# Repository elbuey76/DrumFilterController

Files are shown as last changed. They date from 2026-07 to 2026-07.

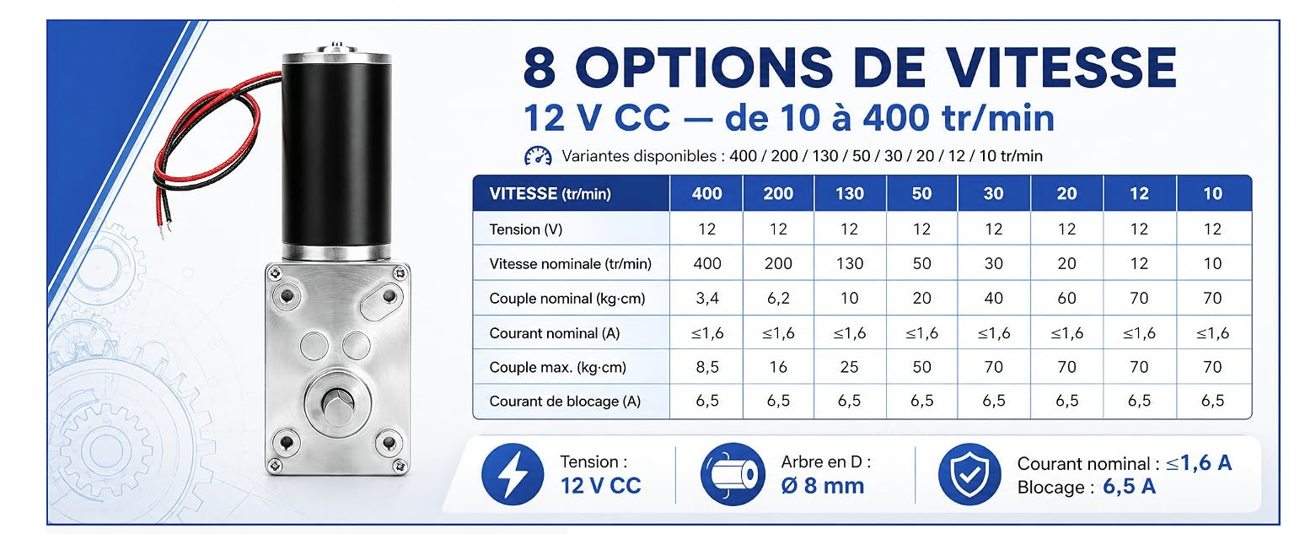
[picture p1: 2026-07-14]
docs/assets/fyearfly-12v-motor-speed-options.png

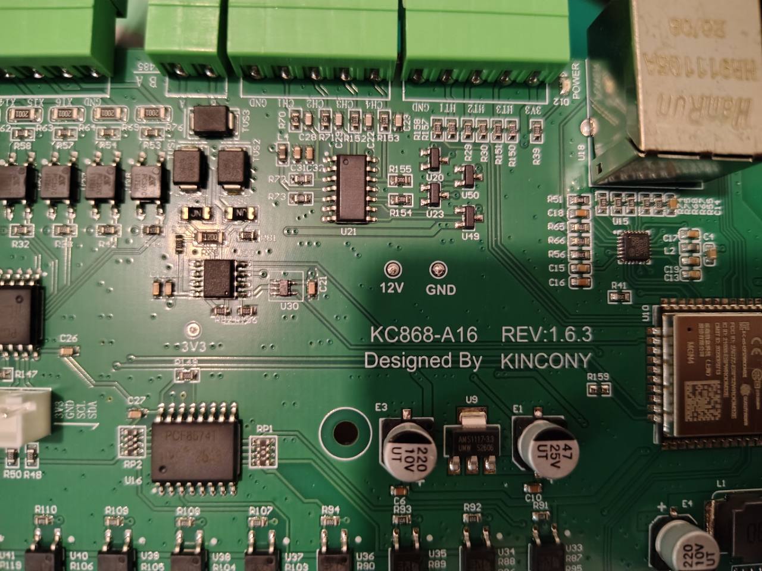
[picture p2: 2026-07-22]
.codex-remote-attachments/019f6168-8cca-70a1-9c1a-e4df0d75bf8c/e161524b-0c4d-4f39-874e-5306fa50447a/1-Photo-1.jpg

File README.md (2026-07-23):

# Contrôleur de filtre à tambour pour bassin

Ce dépôt accueillera la documentation, les schémas, les décisions de conception et le logiciel d'un contrôleur de filtre à tambour pour bassin. L'objectif est de construire un système fiable, maintenable et documenté, basé autant que possible sur des cartes électroniques du commerce, avec la possibilité de concevoir une carte dédiée si le besoin devient justifié.

## Organisation du dépôt

| Dossier | Rôle |
| --- | --- |
| `docs/specification/` | Spécification fonctionnelle, exigences, contraintes et questions ouvertes. |
| `docs/calculs/` | Notes de calcul de dimensionnement hydraulique, mécanique et électrique. |
| `docs/architecture/` | Architecture système, matérielle et logicielle, avec diagrammes et emplacements pour visuels. |
| `docs/decisions/` | Journal de décisions de type ADR pour garder l'historique des choix importants. |
| `docs/achats/` | Listes de course, nomenclatures et points de commande matériel. |
| `docs/backlog/` | Backlog de cadrage, prototype, firmware, documentation et validation. |
| `docs/firmware/` | Plans de réalisation et de découpage du firmware. |
| `docs/validation/` | Plan de tests, traçabilité exigences/preuves et résultats de validation. |

Les documents de spécification et d'architecture sont rédigés en Markdown pour pouvoir combiner texte, tableaux, diagrammes Mermaid et images stockées dans les dossiers `assets/`.

## Objectifs du projet

Le contrôleur doit automatiser le nettoyage d'un filtre à tambour en surveillant le niveau d'eau dans le FAT, puis en déclenchant une rotation du tambour et une pompe de rinçage lorsque le seuil de lavage est atteint. Il doit aussi protéger l'installation en détectant les défauts, couper des prises auxiliaires en cas de niveau bas, permettre un fonctionnement manuel, gérer des modes maintenance, dégradé et test, et redémarrer proprement après une coupure de courant.

Les objectifs principaux sont :

- automatiser les cycles de lavage du tambour ;
- détecter un seuil de niveau haut déclenchant le lavage et un seuil de niveau bas de sécurité ;
- limiter la consommation d'eau et d'énergie ;
- protéger la pompe, le moteur et le bassin en cas de défaut ;
- permettre des modes auto, manuel, maintenance, dégradé et test avec comportements explicites ;
- garder une architecture compréhensible et réparable ;
- préparer une évolution vers journalisation, écran local, supervision réseau et notifications à distance.

## Documents de départ

- [Spécification fonctionnelle](docs/specification/README.md)
- [Notes de calcul](docs/calculs/README.md)
- [Architecture](docs/architecture/README.md)
- [Journal de décisions](docs/decisions/README.md)
- [Achats](docs/achats/README.md)
- [Backlog](docs/backlog/backlog.md)
- [Firmware](docs/firmware/README.md)
- [Validation](docs/validation/README.md)

## Prochaine étape

La validation E/S de la KC868-A16 **REV.1.6.3** recuee est terminee a vide : `X1-X16`, boot OFF et impulsions isolees `Y1-Y16` sont confirmes. Les deux DS18B20 sont lues et associees par ROM. La prochaine etape est le test des voyants et bobines, une par une apres mesure de courant et verification des suppressions de surtension, puis LCD 2004 I2C et RTC DS3231. Le profil materiel reste desarme jusqu'a ces preuves ; voir [VR-0001](docs/validation/VR-0001-reception-kc868-a16-rev1.6.3.md).

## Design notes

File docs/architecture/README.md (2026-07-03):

# Architecture

Ce dossier documenté l'architecture matérielle, électronique et logicielle. Le format principal est Markdown avec schémas Mermaid intégrés et possibilité d'ajouter des images dans `assets/` ou des sources de diagrammes dans `diagrams/`.

## Documents

1. [Vue d'ensemble](01-vue-ensemble.md)
2. [Architecture matérielle](02-architecture-materielle.md)
3. [Architecture logicielle](03-architecture-logicielle.md)
4. [Table des entrées / sorties](04-table-entrees-sorties.md)

## Visuels

- `assets/` : images exportées, photos de prototype, croquis scannés.
- `diagrams/` : sources de diagrammes, par exemple Mermaid, Draw.io ou KiCad exporté.

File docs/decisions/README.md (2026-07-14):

# Journal de décisions

Ce dossier contient les décisions structurantes du projet. Chaque decision importante doit être ajoutée sous forme d'ADR afin de conserver le contexte et les raisons du choix.

## Convention de nommage

```text
ADR-0001-titre-court.md
ADR-0002-titre-court.md
```

## Statuts possibles

- Proposee
- Acceptée
- Remplacée
- Abandonnee

## Modèle rapide

Copier le fichier `_template.md` pour créer une nouvelle decision.

## Decisions disponibles

1. [ADR-0001 - Structurer la documentation projet en Markdown](ADR-0001-structure-documentation.md)
2. [ADR-0002 - Dimensionner la pompe principale sur une pompe variable avec marge](ADR-0002-dimensionnement-pompe-filtration-principale.md)
3. [ADR-0003 - Choix de la plateforme de contrôle V1](ADR-0003-choix-plateforme-controle-v1.md)
4. [ADR-0004 - Architecture electrique V1](ADR-0004-architecture-electrique-v1.md)
5. [ADR-0005 - Choix de la RTC pour l'heure fiable](ADR-0005-choix-rtc-heure-fiable.md)
6. [ADR-0006 - Choix des sondes de temperature](ADR-0006-choix-sondes-temperature.md)
7. [ADR-0007 - Choix du contact de capot](ADR-0007-choix-contact-capot.md)
8. [ADR-0008 - Choix des voyants de l'IHM locale](ADR-0008-choix-voyants-ihm-locale.md)
9. [ADR-0009 - Choix du sélecteur de mode AUTO / MAINTENANCE](ADR-0009-choix-selecteur-mode-auto-maintenance.md)
10. [ADR-0010 - Choix des boutons poussoirs de l'IHM locale](ADR-0010-choix-boutons-poussoirs-ihm-locale.md)
11. [ADR-0011 - Strategie de validation materielle V1](ADR-0011-strategie-validation-materielle-v1.md)
12. [ADR-0012 - Migration de la plateforme KC868-A32 vers KC868-A16](ADR-0012-migration-kc868-a32-vers-a16.md)

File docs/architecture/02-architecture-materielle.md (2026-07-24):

# Architecture matérielle

## Blocs materiels

| Bloc | Rôle | Options envisagées |
| --- | --- | --- |
| Carte de contrôle | Exécute la logique de lavage et sécurité | KC868-A16 ESP32 classique REV.1.6.3 recuee pour la V1 |
| Entrées capteurs | Detectent niveau de lavage, niveau critique, capot, température bassin et température ambiante | Flotteurs, capteurs pression, inductifs, contacts secs, sondes de température |
| Sorties puissance | Pilotent pompe, moteur et prises auxiliaires | Sorties MOSFET 12 VDC vers relais HELLA, contacteurs TOMZN et relais d'interface du contacteur Schneider 230 VAC |
| Interface locale | Permet conduite, signalisation et diagnostic | LCD 2004 / 20x4 I2C 3,3 V, boutons, voyants |
| Communication distante | Option V2 pour supervision et notifications à distance | Wi-Fi cible ; BLE seul insuffisant, Ethernet non disponible sur site, SMS non retenu par défaut |
| Temps fiable | Support futur d'horodatage V2 | Module RTC DS3231 I2C 3,3 V avec batterie rechargeable ; synchronisation réseau possible plus tard en complement, sans dependance exclusive à Internet |
| Alimentation | Fournit basse tension stable | 12 VDC retenu via Mean Well NDR-120-12, 120 W, 10 A |

## Composants materiels deja choisis

| Sous-ensemble | Choix retenu | Impact de conception |
| --- | --- | --- |
| Toile de filtration tambour | Inox 74 microns | Fixe la finesse de filtration mécanique de référence |
| Capteurs de niveau | CR18-8DN | Imposent une interface d'entrée compatible NPN, 12-24 VDC, 3 fils |
| Plateforme de contrôle | KC868-A16 ESP32 classique REV.1.6.3, 16 entrees `X1` a `X16` et 16 sorties MOSFET `Y1` a `Y16` 12/24 VDC | Carte recue et validee a vide le 2026-07-22 ; couvre les 9 entrees et 9 sorties V1 avec 7 voies libres de chaque type ; remplace l'A32 surdimensionnee selon ADR-0012. Les charges et auxiliaires restent a valider. |
| Alimentation 12 VDC | Mean Well NDR-120-12, 120 W, 10 A, rail DIN | Alimente automate, capteurs, IHM, accessoires et moteur tambour via départs fusibles |
| Porte-fusibles 12 VDC | Porte-fusibles ATO 4 emplacements | Distribution 12 VDC ; adaptateur rail DIN imprime 3D realise et fonctionnel |
| Moteur tambour | Motorreducteur Fyearfly 12 VDC 10 rpm | Simplifie la vitesse de tambour par rapport au moteur d'essuie-glace candidat |
| Relais moteur tambour | HELLA 4RD 933 332-551, 12 V, charge inductive 15 A | Commande le moteur tambour ; support rail DIN imprime 3D realise et fonctionnel |
| Pompe de rinçage | VEVOR / Leo EKJ-802S, 220-240 VAC, 800 W indique projet | Impose une commande secteur adaptée à une charge moteur et une mesure du débit réel sur la rampe et les buses déjà achetées et fabriquées |
| Contacteur pompe de rinçage | Schneider Electric TeSys LC1D18P7, 3P, AC-3 18 A, bobine 230 VAC | Sa bobine 230 VAC est commandee par le contact d'un relais d'interface a bobine 12 VDC, lui-meme pilote par une sortie MOSFET A16 ; reference du relais a choisir et valider |
| Contacteurs filtration, UV, décoration, mise à niveau | TOMZN TOCT1-25Z, 25 A, bobine 12 VDC | Pilotés directement en 12 VDC par les sorties MOSFET de l'A16 si la mesure confirme moins de 500 mA par bobine, avec suppression de surtension adaptee |
| Ecran local | LCD 2004 / 20x4 I2C 3,3 V, fond bleu retenu | Afficheur texte principal de l'IHM locale ; raccordement cible sur un bus I2C auxiliaire separe via `GPIO32` / `GPIO33` de l'A16, sans charger le bus I2C interne des entrees/sorties |
| Horloge temps reel | Module RTC DS3231 I2C 3,3 V avec batterie rechargeable | Source locale d'heure fiable pour V2, et horodatage MVP seulement si simple ; adresse I2C attendue `0x68`, raccordement cible sur le bus I2C auxiliaire du port d'extension si la cohabitation avec le LCD est validee |
| Sondes de temperature | 2 x DS18B20 étanches inox 3 fils, longueur cible 3 m | Meme modele pour `TEMP_BASSIN` et `TEMP_LOCAL` ; alimentation 3,3 V, pull-up 4,7 kΩ sur `DATA`. Brochage banc confirme : rouge VCC, noir GND, jaune DATA ; ROMs associees par role. |

## Carte KC868-A16 effectivement recue

La carte disponible est une **Kincony KC868-A16 REV.1.6.3**, a ESP32-WROOM-32 classique. Le test `kc868_a16_hw_safe` du 2026-07-22 a confirme le bus interne `GPIO4/GPIO5` et les quatre adresses `0x21`, `0x22`, `0x24`, `0x25`. Les essais par contact sec ont confirme que `0x22` lit physiquement `X1` a `X8`, puis `0x21` lit `X9` a `X16`. La serigraphie physique utilise `X1` a `X16` pour les entrees et `Y1` a `Y16` pour les sorties MOSFET. Les aliases firmware `I1` a `I9` et `O1` a `O9` suivent respectivement `X1` a `X9` et `Y1` a `Y9`.

Le test a ecrit l'etat brut OFF `0xFF 0xFF` aux deux banques de sorties et le build safe a refuse toute sortie appliquee. Avec les groupes de sorties alimentes en 12 V et sans charge, chaque borne `Y` mesure 100 a 200 mV au boot : l'etat OFF physique est confirme. Les impulsions de banc ont ensuite valide la polarite active et la commande individuelle isolee de `Y1-Y16`. Voir [VR-0001](../validation/VR-0001-reception-kc868-a16-rev1.6.3.md).

## Données hydrauliques d'entrée

L'installation cible a contrôler comprend un FAT avec :

- une emprise interne totale de 78 cm x 47 cm ;
- un trop-plein physique fixe à 30,5 cm de hauteur d'eau ;
- un compartiment eau propre de 62 cm x 47 cm contenant un tambour de 31 cm de diamètre sur 57 cm de longueur utile ;
- deux entrées de 110 mm : une bonde de fond et un skimmer ;
- deux sorties de 110 mm pour conserver le flux hydraulique ;
- une goutiere d'évacuation des dechets rinces vers un tuyau de 100 mm ;
- un report de niveau côté eau propre via un tube de 32 mm ;
- une rampe d'aspersion en 32 mm avec buses.

La rotation du tambour est retenue avec un motorreducteur Fyearfly 12 VDC 10 rpm, en fonctionnement intermittent pendant les cycles de lavage, tests ou commandes manuelles autorisées. Ce choix remplace le candidat initial de moteur d'essuie-glace SWF 403.835 et évite de dépendre d'une réduction mécanique importante pour atteindre une vitesse exploitable.

Le rinçage est envisagé avec une pompe de surface VEVOR / Leo EKJ-802S en 220-240 VAC. La rampe d'aspersion 32 mm et les buses sont déjà achetées et fabriquées ; elles font donc partie du périmètre matériel MVP. La courbe disponible indique environ 3,6 m3/h a très faible hauteur utile et environ 2,4 m3/h à 21 m ; le débit effectif devra être mesuré sur cette rampe réelle.

Le FAT sera installe dans un local de filtration maconne, isole en XPS 5 cm, sans pluie directe sur le FAT. Un capot transparent relevable est prévu au-dessus du petit batiment pour permettre de voir le tambour tourner sans ouvrir le FAT ; ce capot et le couvercle transparent désignent la même pièce physique. Sa matiere et son niveau d'isolation restent à définir.

Ces données doivent être prises en compte pour les choix de capteurs, l'implantation du niveau de lavage côté eau propre, l'ajout d'une mesure de température bassin, l'ajout d'une mesure de température ambiante local et les contraintes de débit autour du filtre.

La liste de signaux à prévoir pour le MVP est détaillée dans [04-table-entrees-sorties.md](04-table-entrees-sorties.md).

## Chaine hydraulique de référence

```mermaid
flowchart LR
    Bassin["Bassin 186 x 411 x 108 cm"]
    BF["Bonde de fond 110 mm"]
    SK["Skimmer 110 mm"]
    FAT["FAT gravitaire"]
    IBC["IBC 1000 L + tapis japonais"]
    PF["Pompe filtration"]
    Retour["Retour bassin 63 mm"]
    PD["Pompe décoration"]
    Deco["Cascade / mur d'eau / lame d'eau"]
    UV["UV hors tambour (apres pompe)"]
    Waste["Goutiere + evacuation 100 mm"]

    Bassin --> BF --> FAT
    Bassin --> SK --> FAT
    FAT --> IBC --> PF --> UV --> Retour --> Bassin
    IBC --> PD --> Deco
    FAT --> Waste
```

## Interfaces mécaniques et instrumentation

| Sous-ensemble | Interface connue | Impact de conception |
| --- | --- | --- |
| Tube de report de niveau | 32 mm, bouche en partie haute avec event de 1 mm | Permet une fixation protégée des deux capteurs côté eau propre EP_LAVAGE et EP_CRITIQUE, et facilite le nettoyage |
| Capteurs de niveau | 2 x CR18-8DN câblés en MVP, M18, distance ajustable 8 mm, sortie NPN normalement ouverte, alimentation 12-24 VDC, 10 mA max, DC 3 fils | EP_LAVAGE au-dessus de EP_CRITIQUE sur supports réglables en hauteur ; réserve mécanique non câblée possible pour un troisième capteur futur ; interface directe sur entrées digitales KC868-A16 retenue par défaut, avec validation banc obligatoire avant câblage final |
| Goutiere de trop-plein | seuil fixe à 30,5 cm | Fixe la cote maximale exploitable pour les seuils de pilotage |
| Support du FAT | a fabriquer | Conditionne tout le régime gravitaire par rapport au bassin |
| Capot | à créer avec fin de course OMRCH ME-8104, contact `1NO1NC` | Ajoute l'entrée de sécurité `CAPOT_OUVERT`. Le montage doit donner capot fermé = boucle fermée, capot ouvert ou fil coupé = boucle ouverte ; choix `NO` ou `NC` à valider au multimètre selon la mécanique réelle. |
| Joint a levre tambour | a poser | Indispensable pour separer correctement eau sale et eau propre |
| Moteur tambour | Fyearfly 12 VDC 10 rpm | Courant réel, couple disponible, sens de rotation et fixation mécanique à valider avant schéma définitif |
| Transmission tambour | A définir autour du motorreducteur 10 rpm | La vitesse finale tambour doit être validée en essai réel ; la réduction 3:1 du candidat SWF n'est plus l'hypothèse de base |
| Protection moteur tambour | Fusible ATO 5 A sur le départ moteur et relais HELLA 12 V 15 A inductif | Courant de blocage annoncé 6,5 A d'après screenshot fournisseur ; calibre 5 A retenu pour essai ; comportement réel de protection à vérifier sur montage MVP |
| Pompe de rinçage | VEVOR / Leo EKJ-802S, raccords 1 pouce, IPX4, classe I | Pompe 230 VAC de surface, a protéger electriquement et a maintenir hors immersion |
| Rampe de rinçage | Tuyau 32 mm + buses déjà achetés et fabriqués | Le point débit/pression réel de la pompe devra être mesuré sur cet ensemble |
| Sonde température bassin | DS18B20 étanche inox 3 fils, longueur cible 3 m | A implanter dans une eau représentative : arrivée gravitaire avant pompe/UV ou bassin en zone brassée, ombragée et accessible ; montage protégé et démontable ; alimentation 3,3 V, pull-up 4,7 kΩ sur `DATA` ; alerte informative en V1 avec seuils initiaux < 4 deg C et > 28 deg C |
| Sonde température ambiante local | DS18B20 étanche inox 3 fils, longueur cible 3 m, même modèle que la sonde bassin | Hors coffret, dans l'air du local, loin de l'alimentation, des contacteurs, des pompes, du soleil et du volume chaud sous capot ; support ventilé et accessible pour conserver une mesure d'air représentative ; alerte informative en V1 avec seuils initiaux < 2 deg C et > 40 deg C |
| IHM locale | LCD 2004 / 20x4 I2C 3,3 V, commandes physiques, voyants MARCHE, ALARME et LAVAGE | L'écran porte le détail ; raccordement cible sur `GPIO32` / `GPIO33` des ports capteurs KC868-A16 via un bus I2C auxiliaire separe ; sélecteur AUTO / MAINTENANCE 22 mm 2 positions maintenues `1NO + 1NC` ; boutons poussoirs 22 mm momentanés `1NO1NC` : reset bleu, test jaune, manuel tambour noir, manuel rinçage noir ; voyants LED étanches 16 mm 12 VDC retenus pour le MVP : MARCHE vert, ALARME rouge et LAVAGE jaune |
| Liaison distante | option V2 Wi-Fi | Le matériel MVP est la base définitive de la V2 et doit être prêt pour une V2 Wi-Fi sans remplacement de plateforme principale ; la notification ne doit pas compromettre le fonctionnement local |
| Horloge fiable | RTC DS3231 retenue, implementation MVP optionnelle | Module RTC DS3231 I2C 3,3 V avec batterie rechargeable, adresse attendue `0x68`. Raccordement cible sur `GPIO32` / `GPIO33` de la KC868-A16 via un bus I2C auxiliaire separe, partage possible avec le LCD 2004 si les essais confirment pull-up 3,3 V, adresses distinctes et stabilite. Sert au temps civil, aux logs et aux statistiques ; les temporisations de securite restent sur timers internes. |
| Position tambour | option V1.1 à étudier | Peut aider pour l'indexation et certains diagnostics avances |

L'UV est retenu hors tambour dans la chaine de filtration, après la pompe principale. Il reste asservi à la filtration autorisée et à l'absence de EP_CRITIQUE ; il n'est pas coupé sur un défaut FAT non critique si la filtration reste autorisée.

## Architecture electrique retenue V1

La decision de reference est [ADR-0004 - Architecture electrique V1](../decisions/ADR-0004-architecture-electrique-v1.md).

La commande matérielle visée correspond au MVP définitif, pas à une commande d'essais séparée. Les validations restantes servent à figer le schéma, les protections, les réglages et l'implantation, en conservant la même plateforme matérielle pour la V2.

### Tableau 230 VAC

| Depart | Protection retenue | Equipements | Commentaire |
| --- | --- | --- | --- |
| Protection amont cote maison | Disjoncteur dedie 16 A | Liaison maison vers coffret filtration | Liaison confirmee en 3G2,5 mm2, actuellement en attente et sans disjoncteur au tableau maison. Le disjoncteur 16 A doit etre ajoute avant le raccordement du coffret. |
| Tete de tableau | Interrupteur differentiel 2P 30 mA, 40 A, type A | Tableau local complet | Choix coherent avec les charges reelles du MVP ; la notice AquaForte DM-Vario demande 30 mA sans imposer type F ou B. |
| Alimentation 12 VDC | Disjoncteur 4 A courbe C | Mean Well NDR-120-12 | Depart dedie au controle basse tension. |
| Pompe de rincage | Disjoncteur 6 A courbe C | Pompe VEVOR / Leo EKJ-802S sur prise 16 A commandee | Commande par contacteur Schneider LC1D18P7, bobine 230 VAC. Le courant nominal pompe est 3,5 A ; le 6 A C remplace le 10 A pour une protection plus ajustee du depart. |
| Prises local | Disjoncteur 16 A courbe C | 1 prise bulleur bassin, 1 prise bulleur bio, 2 prises maintenance | Les bulleurs et prises maintenance sont permanents, hors controleur. |
| Pompe filtration | Disjoncteur 6 A courbe C | Pompe principale sur prise 16 A commandee | Depart separe et prioritaire car organe essentiel. |
| UV, pompe decoration, mise a niveau | Disjoncteur 6 A courbe C | UV et pompe decoration sur prises 16 A commandées ; mise a niveau a definir | Separé de la filtration afin qu'un defaut sur un organe non essentiel ne coupe pas la pompe de filtration. |
| Eclairage exterieur | Disjoncteur 6 A courbe C | 6 spots LED exterieurs 3 W avec detecteurs | Depart distinct hors automatisme FAT ; charge nominale 18 W, soit environ 0,08 A sous 230 VAC, avec environ 10 a 15 m de cable. |

### Distribution 12 VDC

| Depart 12 VDC | Fusible | Usage |
| --- | --- | --- |
| Moteur tambour | 5 A | Motorreducteur Fyearfly 12 VDC 10 rpm via relais HELLA |
| Automate | 3 A | KC868-A16, alimentation principale et deux alimentations des banques de sorties selon schema final |
| Capteurs et boutons | 1 A | Capteurs de niveau, capot et commandes locales |
| Ecran, voyants, accessoires | 1 A | IHM locale, signalisation et accessoires |

Le porte-fusibles ATO devra etre fixe proprement dans le coffret. Les quatre departs 12 VDC proteges partent directement de ce porte-fusibles vers leurs charges : aucun repartiteur +12 V / 0 V supplementaire n'est prevu. Si le modele ATO 4 emplacements est conserve et n'a pas de fixation rail DIN native, un adaptateur imprime en 3D uniquement mecanique sera concu pour assurer le maintien, l'acces aux fusibles, l'absence de contrainte sur les cosses et le reperage des quatre departs.

### Cablage interne basse tension et facade

- Utiliser du fil souple **H07V-K 0,5 mm2** pour les signaux TBT, les capteurs,
  les boutons et les voyants, dans les goulottes basse tension.
- Utiliser du **H07V-K 0,75 mm2** pour l'alimentation de la KC868-A16 et les
  bobines 12 VDC, sous reserve de mesure du courant reel des bobines.
- Le moteur tambour conserve son cable **2 x 2,5 mm2** dedie ; son retour `0 V`
  revient directement vers la distribution 12 VDC et ne partage pas le petit
  commun de commande.
- Pour la porte, utiliser un cable souple multiconducteur **16 x 0,25 ou
  0,34 mm2**, fixe avec serre-cable et boucle de service cote charniere.
- Un unique `0 V` commun de 0,5 mm2 peut etre partage par le LCD, les contacts
  secs du selecteur/boutons et les trois voyants. Les boutons ne recoivent pas
  de 12 V : ils ramenent simplement leur entree KC868-A16 vers ce `0 V`.
- Le LCD reste alimente en **3,3 V** et utilise `SDA` / `SCL`; seuls les voyants
  utilisent les sorties 12 VDC de la KC868-A16. Ne pas employer le bleu pour le
  `0 V` continu, car il est reserve au neutre 230 VAC dans ce coffret.

### Interface des capteurs CR18-8DN

Les entrees digitales du KC868-A16 sont optocouplees et prevues pour des contacts ramenes vers `GND`. Le CR18-8DN fournit une sortie `NPN` collecteur ouvert : marron sur `+12 VDC`, bleu sur `0 V`, noir vers l'entree digitale.

Le cablage direct est retenu en premiere intention pour `EP_LAVAGE` et `EP_CRITIQUE`, sans relais d'interface ni conditionneur supplementaire. Cette decision reste soumise a un test banc avec les vrais capteurs et la revision A16 recue, afin de confirmer le courant d'entree, le sens logique, la stabilite de lecture, le comportement en fil coupe et l'absence de declenchements parasites avec les longueurs de cable reelles.

### Interface du contact de capot

Le contact de capot V1 retenu est un fin de course industriel OMRCH `ME-8104`, momentane, avec contact `1NO1NC`. Il est raccorde comme un contact sec vers `GND` sur une entree digitale du KC868-A16.

Le comportement fonctionnel attendu est : capot ferme = boucle fermee vers l'entree automate ; capot ouvert, fil coupe ou connecteur debranche = boucle ouverte. Le choix pratique entre les bornes `NO` et `NC` du `ME-8104` doit etre valide au multimetre apres montage mecanique, car le nom des bornes decrit l'etat du switch au repos, pas forcement l'etat capot ferme.

Le fin de course doit etre fixe sur la partie fixe du bâti ou du petit batiment, et actionne par une patte ou came reglable solidaire du capot transparent. Le reglage doit eviter qu'un capot entrouvert soit interprete comme ferme.

### Interface de l'ecran local

L'ecran local V1 retenu est un LCD 2004 / 20x4 I2C 3,3 V, fond bleu, avec module I2C de type PCF8574 ou equivalent. Il est alimente par le depart 12 VDC `Ecran, voyants, accessoires` seulement si le module integre une regulation adaptee ; par defaut, son alimentation logique et ses lignes I2C doivent rester compatibles 3,3 V.

Le raccordement cible utilise deux des trois GPIO capteurs de la KC868-A16, avec `GPIO32` et `GPIO33` affectes a un bus I2C auxiliaire separe porte par le second controleur `TwoWire` de l'ESP32. Ce choix evite d'ajouter un peripherique sur le bus I2C interne deja utilise par les PCF8574 des sorties et des entrees digitales. Le brochage de la revision recue et l'ordre exact `SDA` / `SCL` seront figes dans le firmware et le schema apres validation banc.

La validation banc doit verifier l'adresse I2C reelle, probablement `0x27` ou `0x3F`, le contraste, le retroeclairage, la lisibilite en facade, le comportement au redemarrage et l'absence de pull-up vers 5 V sur `SDA` / `SCL`. Si le module recu n'est pas reellement compatible 3,3 V, ajouter un convertisseur de niveau I2C 3,3 V / 5 V ou remplacer le module par une version 3,3 V confirmee.

### Interface de l'horloge RTC

L'heure fiable V2 retenue est un module RTC DS3231 I2C 3,3 V avec batterie rechargeable. Le module doit etre alimente en 3,3 V cote KC868-A16 / ESP32, avec `SDA` et `SCL` tires au 3,3 V uniquement. L'adresse I2C attendue est `0x68`.

Le raccordement cible reutilise le bus I2C auxiliaire separe du port d'extension `GPIO32` / `GPIO33`, partage avec le LCD 2004 I2C si la validation banc confirme la stabilite du bus et l'absence de conflit d'adresse. Si la cohabitation LCD + RTC est instable, la RTC devra etre deplacee sur un autre bus I2C si des GPIO libres le permettent.

La batterie rechargeable livree avec le module sert a conserver l'heure pendant les coupures d'alimentation principale. Le banc doit confirmer que la cellule livree est bien rechargeable, que l'heure est conservee apres coupure et que le module ne presente pas de pull-up I2C vers 5 V.

### Interface des sondes de temperature

Les deux sondes de temperature V1 retenues sont des DS18B20 etanches inox 3 fils, longueur cible 3 m. Le meme modele est utilise pour le bassin et pour le local afin de simplifier l'achat, le stock de rechange, le cablage et le firmware.

Le raccordement retenu est un bus 1-Wire commun alimente en 3,3 V, sans mode parasite : `VCC` sur `3.3 V`, `GND` sur `0 V` commun, `DATA` sur `GPIO14` de la KC868-A16, avec une resistance de pull-up `4,7 kΩ` entre `DATA` et `3.3 V`. Sur la KC868-A16, le bornier utilisateur `HT3` (parfois marque `GPIO3`) correspond a `GPIO14` ; il ne faut jamais utiliser l'entree optocouplee `X14`. Le brochage confirme est rouge = `VCC`, noir = `GND`, jaune = `DATA`. Les ROMs sont figees dans le profil : `TEMP_BASSIN = 28A3AFC800000062`, `TEMP_LOCAL = 284C19CC000000B2`; les deux lectures et leur role ont ete valides par rechauffement doux.

Si des GPIO libres sont disponibles, la preference est de separer `TEMP_BASSIN` et `TEMP_LOCAL` sur deux bus 1-Wire distincts. Si les GPIO sont limites, un bus commun reste acceptable en V1 puisque ces alertes sont informatives et non bloquantes.

Les couleurs de fils annoncees par les vendeurs ne doivent pas etre prises comme reference unique. Le banc doit verifier le brochage reel de chaque lot avant cablage definitif, ainsi que l'identification stable des sondes pour ne pas inverser eau et local dans le firmware.

### Commandes de puissance

| Organe | Commande automate | Organe de puissance retenu | Remarque |
| --- | --- | --- | --- |
| Moteur tambour | Sortie MOSFET A16 12 VDC vers bobine HELLA | Relais HELLA 4RD 933 332-551, 12 V, 15 A inductif | Mesurer le courant de bobine, ajouter la suppression adaptee si absente et imprimer le support rail DIN. |
| Pompe de rincage | Sortie MOSFET A16 vers relais d'interface 12 VDC, puis contact 230 VAC vers bobine LC1D18P7 | Contacteur moteur Schneider TeSys LC1D18P7, AC-3 18 A | Relais d'interface rail DIN a choisir avec contact `AC-15 >= 1 A sous 230 VAC` ; separation BT/secteur obligatoire. |
| Pompe filtration | Sortie MOSFET A16 12 VDC | Contacteur modulaire TOMZN TOCT1-25Z 25 A | Valider courant de bobine inferieur a 500 mA et suppression de surtension. |
| UV | Sortie MOSFET A16 12 VDC | Contacteur modulaire TOMZN TOCT1-25Z 25 A | Valider courant de bobine inferieur a 500 mA ; asservi a la filtration autorisee et a EP_CRITIQUE absent. |
| Pompe decoration | Sortie MOSFET A16 12 VDC | Contacteur modulaire TOMZN TOCT1-25Z 25 A | Valider courant de bobine inferieur a 500 mA ; suit les memes securites hydrauliques que la filtration. |
| Mise a niveau | Sortie MOSFET A16 12 VDC | Contacteur modulaire TOMZN TOCT1-25Z 25 A ou sortie equivalente | Valider courant de bobine inferieur a 500 mA ; coupee sur EP_CRITIQUE. |

## Schéma de principe

```mermaid
flowchart TB
    subgraph BT[Basse tension]
        Alim[Mean Well NDR-120-12]
        Fusibles[Porte-fusibles ATO 4 departs]
        MCU[KC868-A16]
        Inputs[Entrees capteurs]
        UI[Commandes, LCD 2004 I2C et voyants complémentaires]
    end

    subgraph P[Puissance]
        Diff[Differentiel 30 mA]
        DJ[Disjoncteurs 4A, 6A, 10A, 16A]
        KFiltration[Contacteur TOMZN filtration]
        KRincage[Contacteur Schneider rincage]
        KTOMZN[Contacteurs TOMZN UV/deco/mise a niveau]
        KTambour[Relais HELLA tambour]
    end

    Diff --> DJ
    DJ --> Alim
    Alim --> Fusibles
    Fusibles --> MCU
    Fusibles --> KTambour
    Inputs --> MCU
    UI <--> MCU
    MCU --> KFiltration
    MCU --> KRincage
    MCU --> KTOMZN
    MCU --> KTambour
    DJ --> KFiltration
    DJ --> KRincage
    DJ --> KTOMZN
```

## Decisions matérielles a prendre

- reference finale de l'interrupteur differentiel 2P 30 mA, 40 A, type A ;
- cotes exactes EP_LAVAGE et EP_CRITIQUE sur le tube de report après mesure du niveau normal réel ;
- courant réel, fixation et sens de rotation du motorreducteur Fyearfly 12 VDC 10 rpm ;
- validation du fusible 5 A moteur tambour en référence au courant de blocage annoncé 6,5 A, avec mesure du courant en charge et vérification du comportement en blocage ;
- commande secteur de la pompe de rinçage, raccordement à la terre et validation du contacteur Schneider LC1D18P7 dans le schema final ;
- débit ou pression de rinçage de référence après mesure sur la rampe et les buses déjà fabriquées ;
- mesure terrain de la cote support FAT avant fabrication, afin d'aligner trop-plein physique et niveau hydraulique cible du bassin ;
- calcul final de la geometrie des ouvertures du tambour avant découpe ou perçage, avec objectif 0,20 à 0,23 m2 de surface filtrante utile ;
- validation banc des deux sondes DS18B20 étanches inox : brochage réel des fils, alimentation 3,3 V, pull-up 4,7 kΩ, lecture stable, perte de sonde et identification eau/local ;
- validation banc du LCD 2004 I2C 3,3 V : adresse, contraste, lisibilite, pull-up I2C et affectation `GPIO32` / `GPIO33` ;
- validation banc de la RTC DS3231 I2C 3,3 V : adresse `0x68`, batterie rechargeable livree, conservation de l'heure apres coupure, pull-up I2C 3,3 V et cohabitation avec le LCD 2004 sur `GPIO32` / `GPIO33` ;
- validation des références finales des voyants LED étanches 16 mm 12 VDC : MARCHE vert, ALARME rouge et LAVAGE jaune, avec joint de façade, raccordement arrière et profondeur compatibles coffret ;
- architecture Wi-Fi V2 autour du KC868-A16, sans remplacement de plateforme principale ;
- architecture de notification pour une V2 : embarquée, serveur local, service mail ou service push simple ;
- besoin ou non d'un capteur de position tambour ;
- stratégie matérielle d'indexation du tambour hors lavage pour V1.1 ;
- methode empirique d'estimation de la consommation d'eau de rinçage pour V1.1 ou V2 ;
- validation banc de l'interface directe KC868-A16 / CR18-8DN, notamment courant d'entree, sens logique, stabilité, rupture de fil et comportement avec longueurs de câble réelles ;
- validation mecanique et electrique du contact capot OMRCH ME-8104 : bornes a utiliser, capot ferme boucle fermee, capot ouvert ou fil coupe boucle ouverte, alignement de la came et repetabilite ;
- choix des GPIO 1-Wire pour `TEMP_BASSIN` et `TEMP_LOCAL`, bus separes preferes si disponibles ;
- sections de cables retenues en premiere intention : 2 x 2,5 mm2 pour le moteur tambour 12 VDC, 0,5 mm2 pour voyants et boutons, 1,5 mm2 pour les circuits 230 VAC cote filtration y compris cablage interne d'armoire ; borniers, repérage et implantation physique des protections ;
- reference finale materielle du disjoncteur 6 A courbe C pour l'eclairage exterieur, avec validation de la section et du cheminement du cable ;
- adaptateur rail DIN imprime en 3D du porte-fusibles ATO si le composant retenu n'est pas DIN natif ;
- référence finale du coffret, minimum IP55, préférence IP65, avec presse-etoupes et gestion de condensation si necessaire ;
- connecteurs et borniers.

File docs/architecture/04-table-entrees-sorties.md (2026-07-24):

# Table des entrées / sorties

## Objet

Ce document liste les entrées et sorties à prévoir pour le MVP du contrôleur de filtre à tambour. Il sert de base au choix de la carte de contrôle, au schéma de câblage et aux essais sur table.

La table reste une référence de conception. La plateforme KC868-A16 ESP32 classique et les principaux organes de puissance sont retenus pour la commande définitive du MVP selon l'ADR-0012 ; les borniers, sections de cable, repérages et validations de schema restent a figer. La même plateforme matérielle doit rester la base de la V2.

Le noyau E/S V1 est gele fonctionnellement avant le choix de plateforme matérielle. Les références exactes pourront ajouter des marges ou des E/S optionnelles, mais ne doivent pas retirer les signaux Must ci-dessous.

## Conventions

| Champ | Signification |
| --- | --- |
| ID | Repere provisoire de signal. |
| Type | Entrée automate, sortie automate, circuit de puissance ou information IHM. |
| Priorité | `Must`, `Should` ou `Could`, selon les conventions du backlog. |
| État | Niveau de maturite du signal. |
| Interface cible | Technologie pressentie ou contrainte connue. |
| Comportement attendu | Rôle fonctionnel et règles de sécurité associées. |

## Nomenclature physique KC868-A16 recue

La carte effectivement recue est une **Kincony KC868-A16 REV.1.6.3**. Sa serigraphie fait foi pour le cablage : `X1` a `X16` designent les entrees digitales physiques et `Y1` a `Y16` les sorties MOSFET physiques. Les reperes `I` et `O` ci-dessous sont des alias logiques du firmware, pas des etiquettes de bornier.

| Borne physique | Alias firmware | Affectation V1 |
| --- | --- | --- |
| X1 | I1 | `EP_LAVAGE` |
| X2 | I2 | `EP_CRITIQUE` |
| X3 | I3 | `CAPOT_OUVERT` |
| X4 | I4 | `MODE_AUTO` |
| X5 | I5 | `MODE_MAINTENANCE` |
| X6 | I6 | `RESET_ALARME` |
| X7 | I7 | `TEST_LAVAGE` |
| X8 | I8 | `MANU_TAMBOUR` |
| X9 | I9 | `MANU_RINCAGE` |
| X10 a X16 | -- | Reserve V1 |
| Y1 | O1 | `CMD_TAMBOUR` |
| Y2 | O2 | `CMD_RINCAGE` |
| Y3 | O3 | `CMD_POMPE_FILTRATION` |
| Y4 | O4 | `CMD_POMPE_DECO` |
| Y5 | O5 | `CMD_UV` |
| Y6 | O6 | `CMD_MISE_A_NIVEAU` |
| Y7 | O7 | `VOYANT_MARCHE` |
| Y8 | O8 | `VOYANT_LAVAGE` |
| Y9 | O9 | `VOYANT_ALARME` |
| Y10 a Y16 | -- | Reserve V1 |

Le premier scan de la REV.1.6.3 a detecte `0x21`, `0x22`, `0x24` et `0x25` sur le bus I2C interne `GPIO4/GPIO5`. Les contacts secs ont confirme l'ordre `0x22 = X1-X8`, `0x21 = X9-X16`, pris en compte par le profil dedie non valide. Le banc sans charge a aussi confirme l'ecriture brute OFF `0xFF` aux deux banques, la polarite active et l'activation isolee de `Y1` a `Y16`. La preuve detaillee est dans [VR-0001](../validation/VR-0001-reception-kc868-a16-rev1.6.3.md).

## Entrées automate

| ID | Nom | Priorité | État | Interface cible | Comportement attendu |
| --- | --- | --- | --- | --- | --- |
| DI-001 | `EP_LAVAGE` | Must | Retenu, position à régler | CR18-8DN, NPN, 12-24 VDC, 3 fils, support réglable | Premier niveau côté eau propre sur le report 32 mm, placé au-dessus de EP_CRITIQUE. Demande de lavage lorsque le niveau eau propre est abaissé. Le signal doit être filtré par retard configurable avant lancement d'un cycle, cible initiale 5 à 15 s. Si seul ce capteur est douteux, inhiber les lavages automatiques mais maintenir filtration si EP_CRITIQUE est sain. |
| DI-002 | `EP_CRITIQUE` | Must | Retenu, position à régler | CR18-8DN, NPN, 12-24 VDC, 3 fils, support réglable | Deuxième niveau côté eau propre sur le report 32 mm, placé sous EP_LAVAGE. Force la mise en sécurité après anti-rebond très court, cible initiale 0,5 à 2 s : arrêt filtration, arrêt UV, inhibition tambour et rinçage. Toute perte de confiance dans ce signal est bloquante hydraulique. Redémarrage seulement après retour normal stable et acquittement local valide. |
| DI-003 | `CAPOT_OUVERT` | Must | Retenu V1, validation montage à faire | Fin de course OMRCH `ME-8104`, contact `1NO1NC`, raccorde en contact sec vers `GND` sur entree digitale KC868-A16 | Prioritaire sur le sélecteur AUTO / MAINTENANCE. Le capot et le couvercle transparent désignent la même pièce physique. Le montage doit donner capot fermé = boucle fermée ; capot ouvert, fil coupé ou connecteur débranché = boucle ouverte et donc `CAPOT_OUVERT`. Le choix entre borne `NO` ou `NC` doit être validé au multimètre selon la mécanique réelle. Anti-rebond ouverture 100 à 500 ms ; fermeture stable 1 à 2 s avant réautorisation. Capot ouvert hors action dangereuse : afficher `MAINTENANCE - CAPOT OUVERT`, sans acquittement. Après fermeture stable, retour au mode demande si aucune alarme bloquante capot dangereux n'existe. Interdit le lavage automatique, coupe la rotation tambour et le rinçage. L'UV reste asservi à la filtration autorisée et à l'absence de EP_CRITIQUE. Force maintenance ou sécurité selon la situation. |
| DI-004 | `MODE_AUTO` | Must | Retenu V1 | Sélecteur physique `AUTO / MAINTENANCE` type XB2-BD25 ou équivalent, 22 mm, 2 positions maintenues, contact `1NO + 1NC`, voie AUTO raccordée en contact sec vers `GND` sur entrée digitale KC868-A16 | Demande d'exploitation nominale. Ne doit être acceptée que si les sécurités critiques sont saines. Le sens logique exact doit être validé sur banc. |
| DI-005 | `MODE_MANUEL` | Must | Retenu V1 | Boutons poussoirs locaux 22 mm momentanés `1NO1NC`, noirs, `MANU_TAMBOUR` et `MANU_RINCAGE` | Le mode manuel V1 est limité aux commandes FAT ponctuelles, tout en conservant les verrouillages critiques. Les deux boutons noirs doivent être étiquetés clairement en façade. |
| DI-006 | `MODE_MAINTENANCE` | Must | Retenu V1 | Même sélecteur physique que `MODE_AUTO`, voie MAINTENANCE raccordée en contact sec vers `GND` sur entrée digitale KC868-A16 | Inhibe le démarrage automatique du tambour et prepare les interventions. Les deux voies `MODE_AUTO` et `MODE_MAINTENANCE` doivent être mutuellement exclusives après validation câblage. |
| DI-007 | `TEST_LAVAGE` | Must | Retenu V1 | Bouton poussoir local 22 mm momentané `1NO1NC`, jaune, contact `NO` en contact sec vers `GND` sur entrée digitale KC868-A16 | Lance un seul cycle de test autonome borne après appui bref en AUTO ou MAINTENANCE si le capot est fermé, EP_CRITIQUE absent, les capteurs de niveau cohérents et aucun défaut critique bloquant actif. Pas de relances multiples. Verdict `TEST OK - CYCLE EXÉCUTÉ` si EP_LAVAGE était inactif au départ ; verdict selon retour EP_LAVAGE s'il était actif. Refus immédiat avec `A13 - TEST REFUSÉ CAPOT` si capot ouvert, ou `A14 - TEST REFUSÉ SÉCURITÉ` si EP_CRITIQUE, capteurs incohérents ou défaut critique. Arrêt immédiat si capot ouvert, EP_CRITIQUE ou défaut critique apparaît pendant le test. |
| DI-008 | `RESET_ALARME` | Must | Retenu V1 | Bouton poussoir local dédié 22 mm momentané `1NO1NC`, bleu, contact `NO` en contact sec vers `GND` sur entrée digitale KC868-A16 | Acquitte les alarmes lorsque les conditions de retour au service sont satisfaites. Requis après EP_CRITIQUE confirmé, après retour niveau normal stable. L'acquittement distant est réservé à une V2. |
| DI-009 | `MANU_TAMBOUR` | Must | Retenu V1 | Bouton poussoir local 22 mm momentané `1NO1NC`, noir, contact `NO` en contact sec vers `GND` sur entrée digitale KC868-A16 | Demande manuelle de rotation tambour tant que le bouton est maintenu, refusée si capot ouvert, niveau critique ou défaut critique. Refus capot ouvert avec message local simple, sans alarme bloquante si aucune sortie dangereuse n'a démarré. |
| DI-010 | `MANU_RINCAGE` | Must | Retenu V1 | Bouton poussoir local 22 mm momentané `1NO1NC`, noir, contact `NO` en contact sec vers `GND` sur entrée digitale KC868-A16 | Demande manuelle de pompe de rinçage tant que le bouton est maintenu, refusée si capot ouvert, niveau critique ou défaut critique. Refus capot ouvert avec message local simple, sans alarme bloquante si aucune sortie dangereuse n'a démarré. |
| DI-011 | `MANU_POMPE_FILTRATION` | Won't for now | Exclu V1 | Non retenu pour le mode manuel V1 | La pompe principale reste pilotée par les autorisations et sécurités globales, sans commande manuelle independante sur l'IHM V1. |
| DI-012 | `MANU_POMPE_DECO` | Won't for now | Exclu V1 | Non retenu pour le mode manuel V1 | La pompe décoration reste pilotée par les autorisations et sécurités globales, sans commande manuelle independante sur l'IHM V1. |
| DI-013 | `MANU_UV` | Won't for now | Exclu V1 | Non retenu pour le mode manuel V1 | L'UV reste asservi à l'autorisation filtration et à l'absence de niveau critique, sans commande manuelle independante sur l'IHM V1. |
| AI-001 | `TEMP_BASSIN` | Must | Retenu V1, validation banc à faire | DS18B20 étanche inox 3 fils, longueur cible 3 m, alimentation 3,3 V, bus 1-Wire, pull-up 4,7 kΩ vers 3,3 V | Mesure une température représentative de l'eau du bassin, en arrivée gravitaire avant pompe/UV ou directement dans le bassin en zone brassée, ombragée et accessible. Détection de perte de mesure et seuils d'alerte : basse < 4 deg C, haute > 28 deg C. Perte de mesure : `A11 - SONDE EAU ABSENTE`. Alerte informative uniquement en V1. Brochage des couleurs à vérifier sur banc avant cablage. |
| AI-002 | `TEMP_LOCAL` | Must | Retenu V1, validation banc à faire | Même DS18B20 étanche inox 3 fils que `TEMP_BASSIN`, longueur cible 3 m, alimentation 3,3 V, bus 1-Wire, pull-up 4,7 kΩ vers 3,3 V | Mesure la température de l'air du local de filtration, hors coffret, à distance des alimentations, contacteurs, pompes, soleil et volume chaud sous capot. La sonde inox doit être montée sur support ventilé pour représenter l'air du local. Détection de perte de mesure et seuils d'alerte : basse < 2 deg C, haute > 40 deg C. Perte de mesure : `A12 - SONDE LOCAL ABSENTE`. Alerte informative uniquement en V1. Brochage des couleurs à vérifier sur banc avant cablage. |
| DI-014 | `POSITION_TAMBOUR` | Should | Option V2 ou V1.1 tardive | Capteur de position à étudier | Non retenu par défaut en V1.1. À ajouter seulement si l'indexation au temps pose problème ou si une position reproductible devient nécessaire. Non requis et non ajoute en V1 pour rester en diagnostic indirect. |
| AI-003 | `COURANT_TAMBOUR` | Should | Option V1.1 | Capteur de courant DC à étudier plus tard | La protection matérielle surintensité/blocage reste obligatoire en V1. Aucun capteur de courant dédié n'est ajouté en V1 ; seul un contact défaut simple fourni naturellement par le module de protection peut être exploité si cela ne complexifie pas le MVP. |

### Interface électrique KC868-A16 / CR18-8DN

Les capteurs de niveau `EP_LAVAGE` et `EP_CRITIQUE` sont cables directement sur les entrees digitales du KC868-A16, sans relais d'interface par defaut, sous reserve de validation banc.

La KC868-A16 dispose d'entrees digitales optocouplees prevues pour des contacts secs ramenes vers `GND`. La compatibilite electrique avec la sortie collecteur ouvert NPN du CR18-8DN est retenue en premiere intention, mais le courant d'entree et la tension residuelle doivent etre mesures sur la revision A16 recue avant cablage definitif.

La documentation CR18-8DN indique une sortie `NPN` 3 fils, normalement ouverte pour le suffixe `N`, avec alimentation `12-24 VDC`, plage admissible `10-30 VDC`, consommation capteur `10 mA` max, courant de sortie `200 mA` max et tension résiduelle `1,5 V` max. Ces valeurs donnent une marge probable, a confirmer avec le courant reel de l'entree A16.

| Fil CR18-8DN | Fonction | Raccordement V1 |
| --- | --- | --- |
| Marron | Alimentation capteur | `+12 VDC` capteurs, départ fusible 1 A |
| Bleu | 0 V capteur | `GND / 0 V` commun avec les entrées KC868-A16 |
| Noir | Sortie NPN | Entrée digitale KC868-A16, par exemple `X1` (`I1`) pour `EP_LAVAGE` et `X2` (`I2`) pour `EP_CRITIQUE` |

La logique firmware doit considérer ces entrées comme actives quand la sortie NPN tire l'entrée vers 0 V. Le sens logique exact lu via les expanseurs d'E/S de la KC868-A16 doit être vérifié sur banc et inversé en logiciel si nécessaire.

Cette interface directe ne rend pas les capteurs de niveau intrinsèquement fail-safe : une rupture du fil noir ou une absence d'alimentation capteur peut ressembler à un capteur inactif. La V1 compense par cohérence logicielle entre `EP_LAVAGE` et `EP_CRITIQUE`, temporisations prudentes et essais périodiques de validation, mais ne prétend pas détecter toutes les ruptures de ligne sans capteur ou diagnostic supplémentaire.

## Sorties automate et puissance

| ID | Nom | Priorité | État | Interface cible | Comportement attendu |
| --- | --- | --- | --- | --- | --- |
| DO-001 | `CMD_TAMBOUR` | Must | Retenu, validation comportement à faire | Sortie MOSFET KC868-A16 12 VDC vers bobine du relais HELLA 4RD 933 332-551 ; moteur Fyearfly 12 VDC 10 rpm ; fusible 5 A ; courant de blocage annoncé 6,5 A | Commande rotation tambour pendant lavage, test ou manuel autorisé. Mesurer le courant de bobine et ajouter une suppression de surtension si elle n'est pas integree. L'indexation est une extension V1.1. Inhibée en niveau critique, capot ouvert, maintenance ou défaut critique. |
| DO-002 | `CMD_RINCAGE` | Must | Retenu, relais d'interface à choisir | Sortie MOSFET KC868-A16 vers bobine 12 VDC d'un relais d'interface rail DIN ; contact du relais vers bobine 230 VAC du Schneider TeSys LC1D18P7, 3P, AC-3 18 A ; prise 16 A commandee pour pompe VEVOR / Leo EKJ-802S | Commande pompe de rinçage pendant lavage ou test. La pompe conserve sa fiche europeenne et se branche sur la prise commandee. Le relais d'interface doit avoir un contact qualifie pour charge electromagnetique, cible `AC-15 >= 1 A sous 230 VAC`. Le schema final doit assurer separation BT/secteur et reperage du 230 VAC de commande. Inhibée en niveau critique, maintenance incompatible ou défaut critique. |
| DO-003 | `CMD_POMPE_FILTRATION` | Must | Retenu, validation courant à faire | Sortie MOSFET KC868-A16 12 VDC vers contacteur TOMZN TOCT1-25Z 25 A, bobine 12 VDC, puis prise 16 A commandee | Autorise la pompe principale sans couper son cable equipe d'une fiche europeenne. Valider moins de 500 mA par bobine et la suppression de surtension. Coupé en niveau critique, défaut critique ou stratégie de sécurité retenue. Depart 230 VAC separe de l'UV, de la pompe décoration et de la mise à niveau. |
| DO-004 | `CMD_POMPE_DECO` | Must | Retenu, validation courant à faire | Sortie MOSFET KC868-A16 12 VDC vers contacteur TOMZN TOCT1-25Z 25 A, bobine 12 VDC, puis prise 16 A commandee | Autorise la pompe décoration sans couper son cable equipe d'une fiche europeenne. Valider moins de 500 mA par bobine et la suppression de surtension. Suit exactement la même sécurité hydraulique que la pompe principale, car elle aspire au même endroit : OFF sur EP_CRITIQUE. |
| DO-005 | `CMD_UV` | Must | Retenu, validation courant à faire | Sortie MOSFET KC868-A16 12 VDC vers contacteur TOMZN TOCT1-25Z 25 A, bobine 12 VDC, puis prise 16 A commandee | Autorise l'UV seulement si la filtration est autorisée et qu'aucun niveau critique n'est actif, sans couper son cable equipe d'une fiche europeenne. Valider moins de 500 mA par bobine et la suppression de surtension. L'ouverture du capot FAT ne coupe pas l'UV par elle-meme, car l'UV est hors tambour. Après EP_CRITIQUE acquitté, réautorisation après redémarrage filtration et courte stabilisation. |
| DO-006 | `CMD_MISE_A_NIVEAU` | Must | Retenu, validation courant à faire | Sortie MOSFET KC868-A16 12 VDC vers contacteur TOMZN TOCT1-25Z 25 A, bobine 12 VDC ou sortie equivalente selon dispositif final | Valider moins de 500 mA par bobine et la suppression de surtension. Coupé en niveau critique pour éviter un remplissage infini, masquer une fuite ou aggraver une situation hydraulique anormale. |
| DO-007 | `VOYANT_MARCHE` | Must | Retenu V1 | Voyant LED étanche 16 mm, vert, 12 VDC | Indique marche contrôleur, système opérationnel ou auto OK selon le câblage retenu. Complément visuel minimal de l'écran. |
| DO-008 | `VOYANT_AUTO` | Should | À définir | LED, voyant ou IHM | Indique mode auto actif. |
| DO-009 | `VOYANT_MANUEL` | Should | À définir | LED, voyant ou IHM | Indique mode manuel actif. |
| DO-010 | `VOYANT_MAINTENANCE` | Should | À définir | LED, voyant ou IHM | Indique mode maintenance actif. |
| DO-011 | `VOYANT_DEGRADE` | Should | À définir | LED, voyant ou IHM | Indique fonctionnement dégradé. |
| DO-012 | `VOYANT_LAVAGE` | Should | Retenu montage MVP | Voyant LED étanche 16 mm, jaune, 12 VDC | Indique cycle de lavage, test, dégradé ou maintenance si le câblage reste simple. Non bloquant car l'écran affiche le cycle. |
| DO-013 | `VOYANT_ALARME` | Must | Retenu V1 | Voyant LED étanche 16 mm, rouge, 12 VDC | Signale une alarme active, un défaut critique ou `A15 - CAPOT OUVERT LONG`. Pour A15, le voyant rouge est fixe, sans clignotement et sans maintien après fermeture stable du capot. Complément visuel minimal de l'écran, lisible localement. |
| COM-001 | `IHM_ECRAN` | Must | Banc I2C initial validé le 2026-07-23 | LCD 2004 / 20x4 I2C 3,3 V, fond bleu, module I2C type PCF8574 ou equivalent, raccordement sur `GPIO32` / `GPIO33` de la KC868-A16 via un bus I2C auxiliaire separe | Le LCD recu repond a `0x27`, est lisible et affiche l'heure RTC sur le banc partage avec la DS3231. SDA/SCL sont mesures a 3,287 V au repos, sans pull-up externe. La validation de toutes les pages IHM et un essai prolonge restent a faire. |
| COM-002 | `RTC_DS3231` | Must | Banc I2C initial validé le 2026-07-23 | Module RTC DS3231 I2C 3,3 V avec batterie rechargeable, adresse `0x68`, raccordement sur `GPIO32` / `GPIO33` de la KC868-A16 via le bus I2C auxiliaire partage avec le LCD | La RTC recue repond a `0x68`; l'heure et les diagnostics sont fonctionnels, seule puis avec le LCD. Le Wi-Fi/NTP peut recaler la RTC en V2 mais ne doit pas etre l'unique source. Les temporisations de securite et de cycle ne doivent pas dependre de la RTC. |

## Synthèse du noyau E/S V1

### Entrées minimales V1

- `EP_LAVAGE`
- `EP_CRITIQUE`
- `CAPOT_OUVERT`
- sélecteur physique `AUTO / MAINTENANCE` 22 mm, 2 positions maintenues, `1NO + 1NC`
- `RESET_ALARME` bouton poussoir bleu 22 mm momentané `1NO1NC`
- `TEST_LAVAGE` bouton poussoir jaune 22 mm momentané `1NO1NC`
- `MANU_TAMBOUR` bouton poussoir noir 22 mm momentané `1NO1NC`
- `MANU_RINCAGE` bouton poussoir noir 22 mm momentané `1NO1NC`
- `TEMP_BASSIN`
- `TEMP_LOCAL`

### Sorties minimales V1

- `CMD_TAMBOUR`
- `CMD_RINCAGE`
- `CMD_POMPE_FILTRATION`
- `CMD_POMPE_DECO`
- `CMD_UV`
- `CMD_MISE_A_NIVEAU`
- `IHM_ECRAN` LCD 2004 / 20x4 I2C 3,3 V
- `RTC_DS3231` module RTC I2C 3,3 V avec batterie rechargeable pour l'heure fiable V2
- voyant marche vert 16 mm 12 VDC et voyant alarme rouge 16 mm 12 VDC comme complément visuel minimal
- voyant lavage jaune 16 mm 12 VDC retenu pour le montage MVP

Les bulleurs de la cuve bio et du bassin ne sont pas pilotes par le contrôleur. Ils seront branchés directement sur le 220 V et ne doivent pas passer par un circuit coupé par la sécurité niveau critique.

## Groupes de sécurité de puissance

| Groupe | Équipements | Comportement en niveau critique | Remarque |
| --- | --- | --- | --- |
| Groupe coupé sécurité hydraulique | Pompe filtration, pompe décoration, UV, mise à niveau automatique | Coupé ou inhibition | Ces équipements peuvent aggraver une marche à sec, une vidange ou un fonctionnement hors eau. |
| Groupe lavage FAT | Tambour, pompe de rinçage | Inhibe | Aucun lavage ne doit être lance en situation d'eau insuffisante. |
| Protection moteur tambour | Fusible ATO 5 A, relais HELLA 12 V 15 A inductif | Coupure matérielle par fusible ; retour défaut automate non prévu en V1 | Courant de blocage annoncé 6,5 A d'après screenshot fournisseur ; calibre plus restrictif retenu pour essai, comportement à vérifier par démarrage, charge nominale et blocage contrôlé. |
| Protection pompe rinçage | Disjoncteur 6 A courbe C et contacteur Schneider LC1D18P7 | Coupé ou défaut selon architecture retenue | Pompe classe I à raccorder à la terre, courant nominal 3,5 A ; la courbe C tient compte de l'appel moteur. Le contacteur plus calibre ne change pas le calibre de protection. |
| Groupe hors contrôleur | Bulleur cuve bio, bulleur bassin | Non piloté | Alimentation directe 220 V, hors sorties contrôlées et hors circuit coupé par niveau critique. |
| Groupe signalisation | Voyants, écran | Maintenu si possible | La signalisation doit rester disponible pour comprendre l'état de sécurité. |

## Protections électriques retenues

| Circuit | Protection / organe | Remarque |
| --- | --- | --- |
| Protection amont cote maison | Disjoncteur dedie 16 A | Liaison d'environ 20 m entre tableau maison et coffret filtration, confirmee en 3G2,5 mm2. Le cable est en attente et le disjoncteur 16 A doit etre ajoute au tableau maison. |
| Tete de tableau | Interrupteur differentiel 2P 30 mA, 40 A, type A | La notice AquaForte DM-Vario demande une protection 30 mA sans imposer type F ou B ; calibre 40 A coherent avec les charges reelles et les prises maintenance ponctuelles. |
| Alimentation 12 VDC | Disjoncteur 4 A courbe C | Alimente la Mean Well NDR-120-12. |
| Pompe de rincage | Disjoncteur 6 A courbe C | Alimente le depart pompe commande par contacteur Schneider. |
| Prises local | Disjoncteur 16 A courbe C | 1 prise bulleur bassin, 1 prise bulleur filtre bio, 2 prises maintenance ponctuelle. |
| Pompe filtration | Disjoncteur 6 A courbe C | Depart dedie organe essentiel. |
| UV, pompe decoration, mise a niveau | Disjoncteur 6 A courbe C | Depart separe de la filtration. |
| Eclairage exterieur | Disjoncteur 6 A courbe C | Depart dedie hors automatisme FAT, pour 6 spots LED exterieurs de 3 W avec detecteurs ; charge nominale 18 W, environ 0,08 A sous 230 VAC, cable environ 10 a 15 m. |
| Distribution 12 VDC moteur tambour | Fusible ATO 5 A | Moteur Fyearfly via relais HELLA. |
| Distribution 12 VDC automate | Fusible ATO 3 A | KC868-A16, alimentation principale et banques de sorties selon schema final. |
| Distribution 12 VDC capteurs et boutons | Fusible ATO 1 A | Entrees terrain et commandes locales. |
| Distribution 12 VDC IHM et accessoires | Fusible ATO 1 A | Ecran, voyants, accessoires. |
| Fixation porte-fusibles ATO | Adaptateur rail DIN imprime en 3D si necessaire | A prevoir selon le modele exact du porte-fusibles 4 emplacements. |

## Points à arbitrer avant schéma électrique

- Choisir la référence finale de l'interrupteur differentiel 2P 30 mA, 40 A, type A.
- Mesurer les courants des bobines HELLA et TOMZN, verifier la limite de 500 mA par sortie A16 et definir les suppressions de surtension DC.
- Choisir et valider le relais d'interface rail DIN 12 VDC / 230 VAC pour la bobine du LC1D18P7, avec contact cible `AC-15 >= 1 A sous 230 VAC`.
- Valider sur banc le LCD 2004 I2C 3,3 V : adresse, lisibilite, contraste, retroeclairage, affectation `GPIO32` / `GPIO33` et compatibilite des niveaux logiques.
- Valider sur banc la RTC DS3231 I2C 3,3 V : adresse `0x68`, batterie rechargeable livree, conservation de l'heure apres coupure, absence de pull-up vers 5 V et cohabitation avec le LCD 2004 sur le bus I2C auxiliaire separe.
- Valider sur banc les deux DS18B20 etanches inox : brochage reel des couleurs, lecture 3,3 V, pull-up 4,7 kΩ, detection perte de sonde, identification stable eau/local et choix bus 1-Wire separes ou commun.
- Valider le contact capot OMRCH ME-8104 : bornes `NO`/`NC` a utiliser pour obtenir capot ferme = boucle fermee, capot ouvert/fil coupe/connecteur debranche = boucle ouverte, et fonctionnement repetable avec la came du capot.
- Mesurer le courant réel du moteur Fyearfly a vide, en charge et au blocage pour confirmer le fusible 5 A.
- Finaliser les protections, borniers, reperages et cheminements separes entre basse tension et puissance, avec sections retenues en premiere intention : 2 x 2,5 mm2 moteur tambour 12 VDC, 0,5 mm2 voyants et boutons, 1,5 mm2 circuits 230 VAC cote filtration y compris cablage interne d'armoire.
- Valider sur banc la lecture KC868-A16 des deux CR18-8DN : courant d'entree, repos, détection, fil noir débranché, bleu débranché, marron débranché et inversion logique firmware éventuelle.
- Finaliser le support rail DIN imprime en 3D du relais HELLA.
- Finaliser l'adaptateur rail DIN imprime en 3D du porte-fusibles ATO si le modele retenu n'est pas DIN natif.
- Confirmer les références exactes des sondes de température bassin et local.
- Vérifier que les bulleurs alimentés directement en 220 V restent électriquement séparés des circuits coupés par le contrôleur.
- Valider la section, le cheminement et la reference materielle du depart eclairage exterieur protege en 6 A courbe C.
- Évaluer empiriquement la consommation d'eau de rinçage à partir des essais.
- Conserver le capteur de position tambour comme option V2 ou V1.1 tardive tant que l'indexation au temps n'a pas montre de limité.

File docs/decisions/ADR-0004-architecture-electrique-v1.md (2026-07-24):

# ADR-0004 - Architecture electrique V1

## Statut

Acceptee

Amendee par [ADR-0012 - Migration de la plateforme KC868-A32 vers KC868-A16](ADR-0012-migration-kc868-a32-vers-a16.md). Les clauses imposant l'A32 et la commande directe de la bobine 230 VAC du LC1D18P7 sont remplacees par l'A16 a sorties MOSFET et un relais d'interface 12 VDC / 230 VAC. Les autres principes de protection et de distribution restent applicables.

## Contexte

Le controleur du FAT doit separer proprement la distribution secteur 230 VAC, les sorties de puissance et la basse tension 12 VDC. L'installation est dans un local humide protege de la pluie directe, avec des organes essentiels pour la survie du bassin et des organes secondaires qui ne doivent pas pouvoir arreter la filtration principale en cas de defaut.

Les choix ci-dessous documentent l'architecture retenue pour la commande definitive du MVP, avant schema electrique detaille. Les calibres definitifs devront rester coherents avec les caracteristiques constructeur, les longueurs de cables, le coffret retenu et les regles applicables.

## Decision

L'alimentation du coffret FAT doit venir d'un depart dedie cote maison, protege par un disjoncteur 16 A. Ce calibre remplace l'hypothese initiale de 20 A. La liaison existante vers le local filtration fait environ 20 m et sa section est confirmee en 3G2,5 mm2 ; le cable est actuellement en attente sans disjoncteur au tableau maison. Le choix de conserver 16 A limite volontairement le courant total disponible et cette protection doit etre installee avant le raccordement du coffret.

La sequence cible est : disjoncteur 16 A cote maison, interrupteur-sectionneur local TeSys VCDN20 20 A dans le coffret bassin, interrupteur differentiel 30 mA type A 40 A, puis disjoncteurs des departs.

Le tableau 230 VAC local retient l'organisation suivante :

| Depart | Protection retenue | Equipements alimentes | Commentaire |
| --- | --- | --- | --- |
| Coupure generale locale | Schneider Electric TeSys VCDN20, interrupteur-sectionneur 3P, 690 V, 20 A, poignee rouge cadenassable | Ensemble de la partie coffret placee en aval | Utilise comme sectionneur de consignation local, place avant l'interrupteur differentiel du coffret. En monophase, couper phase et neutre avec deux poles ; le troisieme pole reste inutilise ou reserve selon schema final. |
| Tete de tableau | Interrupteur differentiel 2P 30 mA, 40 A, type A | Ensemble du tableau local | Calibre coherent avec les charges reelles du MVP, la pompe AquaForte DM-Vario 20 000 limitee a 187 W, les prises maintenance ponctuelles et les disjoncteurs aval dimensionnes aussi pour les appels moteurs. |
| Alimentation 12 VDC | Disjoncteur 4 A courbe C | Alimentation Mean Well NDR-120-12 | Depart dedie basse tension controle. |
| Pompe de rincage | Disjoncteur 6 A courbe C | Pompe de rincage 230 VAC | Commandee par contacteur moteur Schneider TeSys LC1D18P7, bobine 230 VAC. Son courant nominal connu est 3,5 A ; le 6 A C remplace le 10 A pour une protection plus ajustee, sans que le passage au 18 A AC-3 ne modifie le calibre de protection du depart. |
| Prises local | Disjoncteur 16 A courbe C | 1 prise bulleur bassin, 1 prise bulleur filtre bio, 2 prises maintenance ponctuelle | Les bulleurs restent hors controleur et hors coupure niveau critique. Les prises maintenance servent par exemple aspirateur ou pompe de relevage temporaire. Le courant total disponible reste limite par le disjoncteur amont 16 A cote maison. |
| Pompe filtration | Disjoncteur 6 A courbe C | Pompe principale de filtration | Depart separe car organe essentiel. |
| UV, pompe decoration, mise a niveau | Disjoncteur 6 A courbe C | UV, pompe decoration, mise a niveau automatique | Depart separe de la filtration pour qu'un defaut sur un organe non essentiel ne coupe pas la pompe de filtration. |
| Eclairage exterieur | Disjoncteur 6 A courbe C | 6 spots LED exterieurs de 3 W, avec detecteurs, environ 10 a 15 m de cable | Depart supplementaire distinct, hors automatisme FAT et sans role de securite bassin. La charge nominale est de 18 W, soit environ 0,08 A sous 230 VAC ; le calibre 6 A est retenu comme depart dedie confortable, a confirmer avec la section et les conditions de pose du cable. |

Le TeSys VCDN20 trouve en atelier est donc retenu comme candidat de coupure locale cadenassable du coffret FAT. Il ne remplace ni l'interrupteur differentiel 30 mA ni les disjoncteurs aval. Son integration finale doit verifier l'etat du composant, le schema monophase phase/neutre, le calibre amont 16 A, le pouvoir de coupure adapte aux charges moteur et le maintien des bulleurs hors coupure automatique du controleur.

La basse tension V1 retient une alimentation Mean Well NDR-120-12, 12 VDC, 120 W, 10 A, montee sur rail DIN. Le 12 V est distribue par un porte-fusibles ATO 4 emplacements. Si le modele retenu n'est pas directement compatible rail DIN, un adaptateur imprime en 3D sera prevu pour le fixer proprement dans le coffret :

| Depart 12 VDC | Fusible retenu | Usage |
| --- | --- | --- |
| Moteur tambour | 5 A | Motorisation tambour 12 VDC. |
| Automate | 3 A | KC868-A32. |
| Capteurs et boutons | 1 A | Capteurs, contacts et commandes locales. |
| Ecran, voyants, accessoires | 1 A | IHM locale et signalisation. |

La plateforme de controle retenue est un KC868-A32.

Cette plateforme et cette architecture de puissance constituent la base matérielle MVP et doivent rester compatibles avec la V2 sans remplacement de la plateforme principale.

La motorisation tambour retenue est un motorreducteur Fyearfly 12 VDC, 10 rpm. Elle est commandee par un relais HELLA 12 V, reference 4RD 933 332-551, avec charge inductive 15 A. Un support sera imprime en 3D pour monter proprement ce relais automobile sur rail DIN.

La pompe de rincage est commandee par un relais de l'automate qui pilote directement la bobine 230 VAC d'un contacteur moteur Schneider Electric TeSys LC1D18P7, 3P, 18 A, AC-3. Cette reference remplace le LC1D12P7 car elle est disponible au meme prix, conserve la bobine 230 VAC `P7` et ajoute une marge moteur superieure ; le depart est protege par disjoncteur 6 A courbe C, ajuste au courant nominal pompe connu de 3,5 A. Cette solution est retenue pour eviter d'ajouter un relais intermediaire 12 V -> 230 V et parce que le contacteur equivalent en bobine 12 VDC avec categorie moteur AC-3 est difficile a sourcer ; le schema final devra donc traiter clairement le cheminement 230 VAC de cette commande, la separation BT/secteur et le reperage des borniers.

L'UV, la pompe de decoration et la pompe de filtration sont commandes par les relais de l'automate qui pilotent en 12 VDC des contacteurs modulaires TOMZN TOCT1-25Z, 25 A. Chaque organe conserve sa logique de securite fonctionnelle : la pompe de filtration est separee de la pompe de decoration et de l'UV afin de limiter les defauts communs.

## Consequences

- La tension de commande V1 est maintenant fixee a 12 VDC.
- Le KC868-A32 devient la base du schema de cablage et du futur firmware.
- La commande materielle MVP est definitive dans son principe : les validations restantes portent sur le schema, les interfaces, les sections, les protections et l'implantation, pas sur une plateforme temporaire.
- Le moteur d'essuie-glace SWF 403.835 n'est plus la reference principale de motorisation tambour ; il est remplace par le motorreducteur Fyearfly 12 VDC 10 rpm.
- La separation des departs 230 VAC evite qu'un defaut sur l'UV, la pompe decoration ou la mise a niveau coupe directement le depart de pompe filtration.
- Les bulleurs sont alimentes par les prises classiques du local, mais restent hors sorties controlees afin de maintenir l'aeration independante.
- Le depart cote maison doit etre protege par un disjoncteur 16 A dedie, cote maison. La liaison existante d'environ 20 m est confirmee en 3G2,5 mm2, mais le cable est en attente : le disjoncteur doit etre achete et installe. Ce calibre limite volontairement le courant total disponible du coffret filtration.
- L'interrupteur differentiel de tete est retenu en 2P 30 mA, 40 A, type A. La notice AquaForte DM-Vario impose une protection differentielle 30 mA mais ne demande pas de type F ou B ; le type A est donc retenu comme choix rationnel pour les charges electroniques du MVP.
- Le TeSys VCDN20 trouve en atelier peut etre reutilise comme sectionneur de consignation local avant l'interrupteur differentiel du coffret si son etat mecanique/electrique est sain et si le schema final confirme son cablage.
- Un depart supplementaire d'eclairage exterieur est reserve dans le coffret, protege par disjoncteur 6 A courbe C ; ce circuit n'a pas de role fonctionnel dans le controleur du bassin.
- Les sections de cablage retenues pour le MVP sont : 2 x 2,5 mm2 pour le moteur tambour 12 VDC, 0,5 mm2 pour les voyants et boutons, et 1,5 mm2 pour les circuits 230 VAC cote filtration, y compris dans l'armoire ; ces choix restent soumis a verification du schema final, des longueurs, des conditions de pose et des protections associees.
- La somme des fusibles 12 VDC est maintenant coherente avec l'alimentation 10 A, mais le courant reel reste a mesurer avec moteur, automate, bobines, IHM et voyants actifs.
- Les valeurs de fusibles et disjoncteurs restent a confirmer par revue de schema, fiches constructeur, sections de cable, conditions de pose et essais, notamment l'absence de declenchement intempestif du disjoncteur 4 A courbe C a la mise sous tension de l'alimentation Mean Well.
- Les adaptations imprimees en 3D pour le relais HELLA et le porte-fusibles ATO deviennent des pieces du coffret a concevoir et valider mecaniquement.

## Alternatives considerees

- Garder un seul depart 230 VAC pour filtration, UV et decoration : non retenu, car un defaut sur un organe secondaire pourrait couper la filtration principale.
- Conserver le moteur d'essuie-glace SWF 403.835 : non retenu pour la V1 documentee ici, car le motorreducteur Fyearfly 12 VDC 10 rpm simplifie la reduction mecanique et le dimensionnement de vitesse.
- Commander directement les charges secteur par les relais de l'automate : non retenu pour les charges moteur et les departs de puissance, qui passent par des contacteurs adaptes.
- Retenir un differentiel 63 A ou type F par defaut : non retenu, car les charges reelles du MVP ne justifient pas 63 A et la notice de la pompe de filtration variable ne demande pas de type F. Ces options restent possibles seulement si le schema amont ou un retour terrain les justifie.

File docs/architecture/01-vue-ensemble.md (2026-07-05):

# Vue d'ensemble de l'architecture

## Diagramme de contexte

```mermaid
flowchart LR
    Bassin[Bassin / filtre à tambour]
    Capteurs[Capteurs niveau, capot, températures]
    Controleur[Contrôleur basse tension]
    Puissance[Relais, contacteurs ou variateur]
    Pompe[Pompe de rinçage]
    Moteur[Moteur tambour]
    UI[Boutons, voyants, écran optionnel]

    Bassin --> Capteurs
    Capteurs --> Controleur
    UI <--> Controleur
    Controleur --> Puissance
    Puissance --> Pompe
    Puissance --> Moteur
```

## Principes d'architecture

- Garder la logique de commande en basse tension.
- Isoler clairement la partie puissance.
- Préférer des modules du commerce pour le MVP.
- Documenter toute décision structurante dans le journal de décisions.
- Organiser le firmware autour d'une machine à états testable.

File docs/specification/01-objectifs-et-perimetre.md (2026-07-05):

# Objectifs et périmètre

## Objectif principal

Construire un contrôleur de filtre à tambour pour bassin capable d'automatiser les cycles de lavage, de protéger les équipements, de surveiller la température de l'eau du bassin et la température ambiante du local, et de rester simple a diagnostiquer et a maintenir.

## Résultat attendu

Le projet doit aboutir a :

- une definition claire des fonctions attendues ;
- une architecture matérielle et logicielle documentée ;
- un MVP validable sur table puis sur installation réelle ;
- une base de firmware maintenable ;
- une documentation suffisante pour câblage, configuration, tests et dépannage ;
- une stratégie de mise en sécurité des équipements auxiliaires en cas de niveau bas ;
- une remontée d'alertes utile pour l'exploitation, y compris sur température bassin et température ambiante du local ;
- une IHM locale capable de remonter clairement le statut du système ;
- une préparation explicite d'une capacité de notification à distance de l'état et des alarmes pour une V2.

## Données d'entrée connues

Les données d'entrée suivantes decrivent l'installation cible a prendre en compte pour le dimensionnement et les choix de conception :

- le FAT a une surface interne totale de 78 cm x 47 cm et un trop-plein physique fixe à 30,5 cm de hauteur d'eau ;
- le compartiment eau propre mesure 62 cm x 47 cm et contient un tambour de 31 cm de diamètre sur 57 cm de longueur utile ;
- l'arrivee en eau sale se fait par deux entrées de 110 mm et la sortie en eau propre par deux sorties de 110 mm ;
- la goutiere d'évacuation collecte le debordement et evacue les dechets rinces vers un tuyau de 100 mm ;
- un tube de report de niveau en 32 mm existe deja côté eau propre pour recevoir les capteurs ;
- la ligne de filtration comprend ensuite une cuve IBC de 1000 L pour la biofiltration, une pompe de filtration avec retour en 63 mm, une pompe décoration et un UV hors tambour, dans la filtration, après la pompe principale ;
- une mesure de température bassin doit être ajoutée pour informer l'automate et remonter des alertes ;
- une mesure de température ambiante du local doit être ajoutée pour informer l'automate et remonter des alertes.

Le détail des cotes, volumes théoriques, interfaces et travaux restants est documenté dans [05-donnees-installation-et-fat-existant.md](05-donnees-installation-et-fat-existant.md).

## Périmètre de la première version

La première version couvre :

- détection du besoin de nettoyage par niveau d'eau dans le FAT ;
- séquence de lavage automatique ;
- coupure de prises auxiliaires sur niveau bas de sécurité ;
- mode manuel ;
- temporisations de sécurité ;
- signalisation des états principaux ;
- mise en défaut contrôlée en cas d'anomalie ;
- mesure de température de l'eau du bassin avec remontée d'alertes ;
- mesure de température ambiante du local avec remontée d'alertes ;
- IHM locale de statut ;
- préparation explicite d'une extension de connectivité et de notifications à distance pour une V2.

La frontiere V1 est volontairement stricte : lavage automatique, sécurités niveau et capot, bypass dégradé, IHM locale, températures, reset local et plan de tests trace par exigences.

## Hors périmètre initial

Les points suivants sont envisagéables, mais ne doivent pas bloquer le MVP :

- application mobile ;
- connectivité distante active et notifications associées ;
- supervision cloud ;
- carte électronique entièrement dédiée ;
- historisation longue durée ;
- interface utilisateur avancée ;
- test journalier automatique ;
- statistiques avancées 7 jours / 30 jours ;
- indice d'encrassement ;
- estimation de consommation d'eau ;
- compteurs horaires détaillés, sauf compteur simple ajouté sans risque si le firmware le rend trivial.

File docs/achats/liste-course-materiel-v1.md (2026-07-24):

# Liste de course materiel V1

## Objet

Cette liste consolide les achats a prevoir pour commander le materiel du controleur FAT V1. Elle est basee sur l'architecture materielle, la table d'entrees/sorties, les ADR V1 et la checklist go/no-go.

Elle distingue :

- `A commander` : materiel necessaire si non deja en stock ;
- `A verifier avant commande` : reference, longueur ou dimension a confirmer ;
- `Spare recommande` : piece de rechange utile pour depannage et essais.
- `Commande 2026-07-06` : article commande, attente de reception puis controle banc ou inspection ;
- `Deja disponible` : article annonce en stock, inspection et validation encore necessaires avant montage.

Les circuits 230 VAC doivent etre finalises sur schema et relus par une personne competente avant mise sous tension.

Le journal de commande detaille est dans [commandes-2026-07-06.md](commandes-2026-07-06.md).

## 1. Controle, alimentation 12 VDC et distribution

| Qté | Article | Reference / caracteristiques | Statut | Notes |
| ---: | --- | --- | --- | --- |
| 1 | Carte de controle cible | KC868-A16 ESP32 classique REV.1.6.3 a sorties MOSFET | Deja disponible, validation banc en cours | Carte recue le 2026-07-22 ; scan interne `0x21/0x22/0x24/0x25` et demarrage safe documentes. Bornes physiques : entrees `X1-X16`, sorties `Y1-Y16`. |
| 1 | Ancienne carte de controle | KC868-A32 / variante A32G | Abandonnee pour le FAT | Commandee le 2026-07-06 pour 121,99 EUR puis retiree de la conception cible car surdimensionnee ; retour, revente ou reutilisation a decider. |
| 1 | Alimentation rail DIN | Mean Well NDR-120-12, 12 VDC, 120 W, 10 A | Commande 2026-07-06 | Alimente automate, capteurs, IHM, contacteurs 12 VDC et moteur via fusibles. |
| 1 | Porte-fusibles DC 4 departs | ATO 4 emplacements, idealement rail DIN natif | Commande 2026-07-06 | Variante 6 voies commandee ; si modele non DIN, prevoir adaptateur imprime 3D. |
| 5 | Fusibles ATO 5 A | Depart moteur tambour | Commande 2026-07-06 | Quantites et calibres reels a verifier a reception. |
| 5 | Fusibles ATO 3 A | Depart automate | Commande 2026-07-06 | Quantites et calibres reels a verifier a reception. |
| 10 | Fusibles ATO 1 A | Departs capteurs/boutons et IHM/accessoires | Commande 2026-07-06 | Quantites et calibres reels a verifier a reception. |

## 2. Capteurs et instrumentation

| Qté | Article | Reference / caracteristiques | Statut | Notes |
| ---: | --- | --- | --- | --- |
| 3 | Capteurs de niveau | CR18-8DN, NPN, 12-24 VDC, M18, 3 fils | Deja disponible | 2 installes : `EP_LAVAGE`, `EP_CRITIQUE`. Le 3e est le spare recommande ; valider l'interface KC868-A16 avant cablage definitif. |
| 2 | Supports reglables capteurs M18 | Equerres, colliers ou support maison reglable en hauteur | A verifier avant commande | Pour tube de report niveau 32 mm ; prevoir nettoyage et reglage accessibles. |
| 1 | Reserve support 3e capteur | Support mecanique ou emplacement libre | A verifier avant commande | Reserve V1.1/V2, pas de cablage V1 obligatoire. |
| 1 | Fin de course capot | OMRCH ME-8104, momentane, contact 1NO1NC | Commande 2026-07-06 | Montage fail-safe : capot ferme = boucle fermee ; quantite et bornes a verifier. |
| 1 | Came / patte de capot | Patte reglable pour actionner le ME-8104 | A verifier avant commande | Peut etre fabriquee localement. |
| 3 | Sondes temperature | DS18B20 etanche inox, 3 fils, longueur cible 3 m | Deja disponible | 2 installees : eau + local. Le 3e est le spare recommande ; verifier le brochage et la longueur de cable. |
| 10 | Resistances | 4,7 kOhm, 1/4 W | Deja disponible | Pull-up bus 1-Wire vers 3,3 V. |
| 1 | Module RTC | DS3231 I2C compatible 3,3 V, batterie rechargeable incluse | Commande 2026-07-06 | Adresse attendue `0x68`, pull-up I2C 3,3 V a verifier. |

## 3. Interface locale en facade

| Qté | Article | Reference / caracteristiques | Statut | Notes |
| ---: | --- | --- | --- | --- |
| 1 | Ecran LCD | LCD 2004 / 20x4 I2C, compatible 3,3 V, fond bleu | Commande 2026-07-06 | Adresse probable `0x27` ou `0x3F`; verifier absence de pull-up 5 V. |
| 1 | Selecteur AUTO / MAINTENANCE | Type XB2-BD25 ou equivalent, 22 mm, 2 positions maintenues, 1NO + 1NC | Commande 2026-07-06 | Deux entrees : `MODE_AUTO` et `MODE_MAINTENANCE`. |
| 1 | Bouton reset | 22 mm momentane, bleu, 1NO1NC | Commande 2026-07-06 | `RESET_ALARME`. |
| 1 | Bouton test | 22 mm momentane, jaune, 1NO1NC | Commande 2026-07-06 | `TEST_LAVAGE`. |
| 2 | Boutons manuel | 22 mm momentanes, noirs, 1NO1NC | Commande partielle 2026-07-06 | `MANU_TAMBOUR` et `MANU_RINCAGE`, etiquettes obligatoires ; verifier si un second noir est inclus ou a commander. |
| 1 | Bouton de rechange | 22 mm momentane, 1NO1NC, couleur au choix hors rouge/vert si possible | Spare recommande | Piece de depannage. |
| 1 | Voyant marche | LED etanche 16 mm, vert, 12 VDC | Commande 2026-07-06 | `VOYANT_MARCHE`. |
| 1 | Voyant alarme | LED etanche 16 mm, rouge, 12 VDC | Commande 2026-07-06 | `VOYANT_ALARME`. |
| 1 | Voyant lavage | LED etanche 16 mm, jaune, 12 VDC | Commande 2026-07-06 | `VOYANT_LAVAGE`. |
| 1 | Voyant de rechange | LED etanche 16 mm, 12 VDC, rouge ou jaune | Spare recommande | Choisir une couleur utile au depannage. |
| 1 lot | Etiquettes facade | AUTO, MAINTENANCE, RESET ALARME, TEST LAVAGE, MANU TAMBOUR, MANU RINCAGE, MARCHE, ALARME, LAVAGE | A commander | Preferer etiquettes gravees/plastifiees durables. |

## 4. Commande de puissance et actionneurs

| Qté | Article | Reference / caracteristiques | Statut | Notes |
| ---: | --- | --- | --- | --- |
| 1 | Motorreducteur tambour | Fyearfly 12 VDC, 10 rpm | Commande 2026-07-06 | Mesurer courant a vide, en charge, demarrage et blocage. |
| 1 | Relais moteur tambour | HELLA 4RD 933 332-551, 12 V, charge inductive 15 A | Commande 2026-07-06 | Support rail DIN imprime 3D realise et fonctionnel. |
| 1 | Support rail DIN relais HELLA | Piece imprimee 3D ou support compatible | Fabrique et fonctionnel | Maintien mecanique, acces cosses et reperage valides. |
| 1 | Pompe de rincage | VEVOR / Leo EKJ-802S, 220-240 VAC | Deja disponible | Pompe classe I, terre obligatoire, debit reel a mesurer sur rampe. |
| 1 | Relais d'interface pompe rincage | Bobine 12 VDC < 500 mA, support rail DIN, contact cible AC-15 >= 1 A sous 230 VAC, suppression de bobine | A choisir avant commande | La sortie MOSFET A16 commande la bobine 12 VDC ; le contact du relais commande la bobine 230 VAC du LC1D18P7. |
| 1 | Contacteur pompe rincage | Schneider Electric TeSys LC1D18P7, 3P, AC-3 18 A, bobine 230 VAC | Commande 2026-07-06 | Remplace le LC1D12P7 a prix equivalent : meme bobine 230 VAC, marge moteur superieure. Commande via relais d'interface 12 VDC / 230 VAC ; separation BT/secteur a soigner. |
| 4 | Contacteurs auxiliaires 12 VDC | TOMZN TOCT1-25Z, 25 A, bobine 12 VDC | Commande 2026-07-06 | Filtration, UV, decoration, mise a niveau. |
| 1 | Contacteur auxiliaire de rechange | TOMZN TOCT1-25Z 12 VDC ou alternative validee | Spare recommande | Si budget/place disponible. |

## 5. Protections et tableau 230 VAC

| Qté | Article | Reference / caracteristiques | Statut | Notes |
| ---: | --- | --- | --- | --- |
| 1 | Coupure generale locale | Schneider Electric TeSys VCDN20, interrupteur-sectionneur 3P, 690 V, 20 A, poignee rouge cadenassable | Deja disponible | Sectionneur annonce en stock ; verifier reference exacte, etat, calibre, poles, verrouillage et compatibilite coffret. |
| 1 | Interrupteur differentiel | 2P, 30 mA, 40 A, type A | A commander | Reference finale a choisir dans la gamme tableau retenue. |
| 1 | Disjoncteur alimentation 12 V | 4 A courbe C | A commander | Depart Mean Well NDR-120-12. |
| 1 | Disjoncteur pompe rincage | 6 A courbe C | A commander | Pompe EKJ-802S de courant nominal 3,5 A, commandee via contacteur Schneider. Le 6 A C laisse la marge necessaire au demarrage et protege plus finement le depart qu'un 10 A. |
| 1 | Disjoncteur prises local | 16 A courbe C | A commander | Bulleurs et prises maintenance, hors controleur. |
| 1 | Disjoncteur pompe filtration | 6 A courbe C | A commander | Depart separe organe essentiel. |
| 1 | Disjoncteur UV / decoration / mise a niveau | 6 A courbe C | A commander | Depart separe de la filtration. |
| 1 | Disjoncteur eclairage exterieur | 6 A courbe C | A commander | Depart dedie, hors automatisme FAT. |
| 8 | Prises 16 A 2P+T | Adaptees au local humide, IP44 minimum et IP55 prefere | A commander | 4 prises commandees : rincage, filtration, decoration, UV. 4 prises permanentes : 2 bulleurs et 2 maintenance. Les appareils a fiche europeenne ne sont pas recables. |
| 1 | Disjoncteur amont maison | 16 A dedie, compatible avec le tableau maison et sa gamme | A commander et faire installer | Le cable maison-local est present en attente et confirme en 3G2,5 mm2, mais aucun depart n'est actuellement protege au tableau maison. Ajouter ce disjoncteur avant tout raccordement du coffret FAT. |
| 1 lot | Peignes / pontages / obturateurs | Compatibles avec la gamme de disjoncteurs choisie | A commander | Garder une gamme coherente pour le tableau. |

## 6. Coffret, rail DIN et implantation

| Qté | Article | Reference / caracteristiques | Statut | Notes |
| ---: | --- | --- | --- | --- |
| 1 | Coffret electrique plastique | IP65 minimum ; cible environ 800 x 600 x 300 mm, polyester renforce ou polycarbonate industriel, porte compatible facade IHM | A verifier avant commande | Enveloppe non metallique imperative pour le Wi-Fi. Capacite minimale calculee 58 emplacements equivalents, sectionneur de facade exclu ; quatre rails de 450 a 500 mm. La taille est imposee aussi par les goulottes, les profondeurs et le Wi-Fi. Candidat : Schneider NSYPLM86BG, IP66/IK10, 847 x 636 x 300 mm, platine bakelite. Voir [NC-0005](../calculs/NC-0005-dimensionnement-coffret-electrique.md). |
| 1 | Platine de fond | Compatible coffret | A commander si non incluse | Pour fixer rail DIN, goulottes, borniers et supports. |
| 4 | Rails DIN | 35 mm, longueur utile 450 a 500 mm | A verifier avant commande | Implantation cible : protections, puissance, controle/12 VDC et borniers. |
| 2 a 4 | Goulottes cable | Avec couvercles, dimensions selon coffret | A verifier avant commande | Separation cheminements BT/secteur. |
| 15 | Presse-etoupes IP68 | 5 M16, 9 M20 et 1 M25, avec contre-ecrous | A commander | 13 sorties actives, 1 arrivee maison 3G2,5 mm2 et 1 reserve. Verifier les diametres reels de cable avant commande. |
| 1 lot | Bouchons de presse-etoupe | Compatibles diametres non utilises | A commander | Pour reserve propre et etanche. |
| 1 | Event / traitement condensation | Event respirant ou solution passive adaptee au coffret | A verifier avant commande | Local humide, condensation a traiter. |

## 7. Borniers, raccordement et reperage

| Qté | Article | Reference / caracteristiques | Statut | Notes |
| ---: | --- | --- | --- | --- |
| 8 | Borniers passage gris | Rail DIN, 2,5 mm2, 230 VAC phase | A commander | 1 arrivee maison et 7 departs puissance sortants. |
| 8 | Borniers neutre bleus | Rail DIN, 2,5 mm2 | A commander | 1 arrivee maison et 7 departs puissance sortants. |
| 8 | Borniers terre vert/jaune | Rail DIN, 2,5 mm2 | A commander | 1 arrivee maison et 7 departs puissance sortants. |
| 16 | Borniers passage blancs | Rail DIN, 2,5 mm2, TBT | A commander | Moteur tambour 12 VDC, capteurs niveau, capot et sondes temperature. |
| 1 lot | Pontages borniers | Compatibles borniers choisis | A commander | Distribution propre +12 V, 0 V, phase/neutre selon schema. |
| 1 lot | Reperes borniers et fils | Numerotation, etiquettes ou bagues | A commander | Indispensable pour maintenance et validation. |
| 1 lot | Embouts de cablage | 0,5 / 0,75 / 1,5 / 2,5 mm2 | A commander | Pour fils souples H07V-K. |
| 1 lot | Cosses plates isolees | 6,3 mm et formats necessaires au relais HELLA / accessoires | A commander | A confirmer avec les bornes reelles. |
| 1 lot | Cosses oeillet / fourche | Pour terre et raccordements a vis | A commander | Dimensions a adapter aux bornes finales. |
| 1 lot | Gaine thermoretractable | Plusieurs diametres | A commander | Finitions et isolations locales. |
| 1 lot | Colliers, bases autocollantes, visserie | Nylon/inox selon environnement | A commander | Maintien des cables et petites fixations. |

## 8. Cables et fils

Les longueurs exactes doivent etre mesurees sur site avant commande. Les sections ci-dessous reprennent l'intention V1 documentee ; elles restent a verifier avec le schema final, les longueurs et les protections.

| Qté | Article | Reference / caracteristiques | Statut | Notes |
| ---: | --- | --- | --- | --- |
| A mesurer | Fil interne 230 VAC | H07V-K 1,5 mm2, marron/noir, bleu, vert-jaune | A commander | Cablage interne armoire et departs 230 VAC. |
| A mesurer | Fil interne basse tension | H07V-K souple : 0,5 mm2 pour TBT/signaux, 0,75 mm2 pour alimentation A16 et bobines 12 VDC | A commander | Couleurs : rouge `+12 V`, noir `0 V`, blanc signaux TBT. Ne pas utiliser le bleu, reserve au neutre 230 VAC. |
| A mesurer | Cable souple de porte | 16 x 0,25 ou 0,34 mm2, cable de commande multiconducteur | A commander | 13 ames utiles : LCD 3,3 V/I2C, selecteur, 4 boutons, 3 voyants et 0 V commun ; 3 ames de reserve. |
| A mesurer | Cable moteur tambour | 2 x 2,5 mm2 ou cable adapte environnement | A verifier avant commande | Section retenue en premiere intention pour moteur 12 VDC. |
| A mesurer | Cable departs 230 VAC terrain | 3G1,5 mm2 adapte local humide / exterieur selon pose | A verifier avant commande | Pompe rincage, filtration, UV, decoration, mise a niveau, prises. |
| 10 a 15 m | Cable eclairage exterieur | Section et type a confirmer selon pose | A verifier avant commande | Depart eclairage 6 spots LED 3 W avec detecteurs. |
| A mesurer | Rallonges capteurs | Cable 3 fils 0,34 a 0,75 mm2, ou connectique etanche adaptee | A verifier avant commande | Pour CR18-8DN et DS18B20 si cables d'origine insuffisants. |

## 9. Pieces mecaniques et hydrauliques a verifier

| Qté | Article | Reference / caracteristiques | Statut | Notes |
| ---: | --- | --- | --- | --- |
| 1 | Toile tambour | Inox 74 microns | A verifier stock | Reference de filtration retenue. |
| 1 | Joint a levre tambour | Dimension selon tambour | A verifier avant commande | Indispensable separation eau sale / eau propre. |
| 1 | Tube report niveau | PVC 32 mm avec event 1 mm | A verifier stock | Support des capteurs de niveau. |
| 1 | Rampe de rincage | Tuyau 32 mm + buses | Deja achete/fabrique selon doc | Verifier que tout le raccordement est complet. |
| 1 lot | Raccords pompe rincage | Raccords 1 pouce, clapet/vanne si schema hydraulique le demande | A verifier avant commande | Adapte a la VEVOR / Leo EKJ-802S. |
| 1 | Support FAT | Structure a fabriquer | A verifier avant commande | Conditionne les niveaux gravitaires. |
| 1 | Capot transparent | Matiere et isolation a definir | A verifier avant commande | Doit actionner le ME-8104 et permettre l'inspection visuelle. |

## 10. Materiel hors controleur a confirmer

Ces elements sont cites dans l'architecture mais peuvent deja exister sur l'installation. Ne les commander que si le stock/projet les confirme manquants.

| Qté | Article | Reference / caracteristiques | Statut | Notes |
| ---: | --- | --- | --- | --- |
| 1 | Pompe principale de filtration | AquaForte DM-Vario 20 000 ou reference existante | A verifier stock | Depart dedie 6 A. |
| 1 | UV | Reference existante, hors tambour apres pompe | A verifier stock | Asservi a la filtration et EP_CRITIQUE absent. |
| 1 | Pompe decoration | Reference existante | A verifier stock | Coupee sur EP_CRITIQUE. |
| 1 | Mise a niveau automatique | Dispositif final a confirmer | A verifier stock | Coupee sur EP_CRITIQUE. |
| 2 | Bulleurs | Bassin + filtre bio | A verifier stock | Alimentes directement, hors sorties controlees. |
| 4 | Prises local | 2 bulleurs + 2 maintenance | A verifier avant commande | Prises compatibles local technique humide. |

## 11. Minimum de rechange a avoir dans le coffret

| Qté | Piece de rechange | Notes |
| ---: | --- | --- |
| 1 | CR18-8DN | Niveau lavage ou critique. |
| 1 | DS18B20 | Eau ou local. |
| 1 | Bouton 22 mm 1NO1NC | Remplacement reset/test/manuel selon couleur disponible. |
| 1 | Voyant 16 mm 12 VDC | Rouge ou jaune prioritaire. |
| 1 | Contacteur TOMZN TOCT1-25Z 12 VDC | Si budget/place disponible. |
| 1 lot | Fusibles ATO 1 A / 3 A / 5 A | A garder dans un sachet repere. |

## 12. Points a confirmer avant validation panier

- Reference exacte du coffret plastique IP65 : cible recommandee 800 x 600 x 300 mm environ, quatre rails utiles de 450 a 500 mm, platine isolante de preference et zone radio libre autour de l'antenne KC868-A16. Le bilan detaille est dans [NC-0005](../calculs/NC-0005-dimensionnement-coffret-electrique.md).
- Reference finale de l'interrupteur differentiel 2P 30 mA 40 A type A et coherence de gamme avec les disjoncteurs.
- Etat reel du sectionneur TeSys VCDN20 trouve en atelier.
- Longueurs de cables terrain : moteur tambour, capteurs, sondes, pompe rincage, filtration, UV, decoration, mise a niveau, prises et eclairage.
- Diametre des cables pour choisir correctement les presse-etoupes.
- Validation de l'interface directe KC868-A16 / CR18-8DN avant cablage definitif.
- Compatibilite 3,3 V reelle du LCD 2004 I2C et du module DS3231.
- Brochage reel des DS18B20 et couleurs de fils du lot recu.
- Revue du schema 230 VAC avant achat final si les references tableau changent.

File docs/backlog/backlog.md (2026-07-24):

# Backlog projet

## A cadrer

| ID | Element | Priorité | Statut |
| --- | --- | --- | --- |
| B-001 | Consolider sur le montage MVP les caractéristiques du moteur de tambour retenu Fyearfly 12 VDC 10 rpm : courant a vide, courant en charge, courant au démarrage, comportement en blocage avec courant annoncé 6,5 A, couple utile et vitesse finale tambour. | Must | En cours |
| B-002 | Consolider les caractéristiques de la pompe de rinçage VEVOR / Leo EKJ-802S et mesurer son point de fonctionnement réel sur la rampe et les buses déjà achetées et fabriquées. | Must | En cours |
| B-003 | Définir l'implantation des deux capteurs CR18-8DN V1, EP_LAVAGE et EP_CRITIQUE, en prévoyant une réserve mécanique pour un éventuel troisieme capteur futur si les essais le justifiént. | Must | Tranchée |
| B-004 | Définir l'environnement du coffret et l'indice de protection attendu. | Must | Tranchée |
| B-005 | Définir les cotes exactes du niveau normal côté sale, du niveau normal côté propre, du seuil de lavage et du niveau bas sur le tube de report en 32 mm. | Must | À faire |
| B-006 | Mesurer sur site la hauteur finale du support du FAT par rapport au niveau hydraulique du bassin avant fabrication. | Must | À faire |
| B-007 | Determiner si la logique de lavage repose sur une cote simple côté propre, sur une comparaison sale/propre, ou sur une combinaison des deux. | Must | Tranchée |
| B-008 | Ajouter des reperes visuels de niveau pour identifier d'un coup d'oeil l'état hydraulique du FAT, par exemple avec de petites cales plastiques collees aux niveaux de référence. | Should | À faire |
| B-009 | Prévoir un bypass passif ou mécanique entre eau sale et eau propre permettant de maintenir le passage vers la biofiltration en mode survie quand le lavage FAT est indisponible, tant que le niveau eau propre n'est pas critique. | Must | À faire |
| B-010 | Valider l'hypothèse de niveau normal côté sale autour de 20 cm au-dessus du bas du tambour soit environ 27 cm depuis le fond, avec ses reperes associés environ 64,5 % du diamètre en hauteur, environ 59 % de circonference immergée et environ 58 cm de longueur developpee immergée. | Must | À faire |
| B-011 | Calculer et valider avant découpe la forme, le nombre et la surface totale des ouvertures du tambour afin d'obtenir une surface de filtration utile d'environ 0,20 à 0,23 m2. | Must | À faire |
| B-012 | Définir precisement les modes auto, manuel, maintenance, dégradé, test et arrêt total avec leurs transitions autorisées. | Must | À faire |
| B-013 | Définir la politique de reprise après coupure de courant pour chaque mode et chaque sortie, avec reprise normale, reprise EP_LAVAGE seule et blocage EP_CRITIQUE. | Must | Tranchée |
| B-014 | Retenir la liste minimale d'auto-diagnostics indirects V1 : EP_CRITIQUE, incohérence niveau, lavage inefficace après 3 tentatives, capot dangereux, A15, commande UV incohérente, perte sondes température ; reporter absence anormale de lavage, lavage trop fréquent, moteur bloque, pompe rinçage HS et pression absente. | Must | Tranchée |
| B-015 | Garder le mode hiver automatique hors V1 ; conserver seulement les alertes température eau/local en V1 et reetudier les adaptations hiver en V1.1/V2 après observation réelle. | Should | Tranchée |
| B-016 | Définir la fonction de mesure de température bassin : sonde DS18B20 étanche inox 3 fils, longueur cible 3 m, implantation représentative de l'eau du bassin, plage utile et seuils d'alerte informative V1 < 4 deg C et > 28 deg C. | Must | Tranchée |
| B-017 | Définir la fonction de mesure de température ambiante local : même sonde DS18B20 étanche inox 3 fils que pour le bassin, montée en support ventilé dans l'air du local, plage utile et seuils d'alerte informative V1 < 2 deg C et > 40 deg C. | Must | Tranchée |
| B-022 | Figer les paramètres de lavage auto mini 10 s, maxi 45 s, rotation résiduelle 2 à 5 s, anti-redémarrage 30 à 120 s, 3 tentatives, pause 30 à 120 s, seuils horaire et journalier, avec retard EP_LAVAGE initial 5 à 15 s et confirmation EP_CRITIQUE initiale 0,5 à 2 s. | Must | En cours |
| B-018 | Retenir une IHM locale V1 avec LCD 2004 / 20x4 I2C 3,3 V, fond bleu, et commandes physiques essentielles. | Must | Tranchée |
| B-019 | Retenir les voyants complémentaires V1 du montage MVP : MARCHE vert, ALARME rouge et LAVAGE jaune, en voyants LED étanches 16 mm 12 VDC, en gardant l'écran comme support principal de lecture des états. | Should | Tranchée |
| B-020 | Retenir pour une V2 une remontée distante Wi-Fi avec notifications actionnables : EP_CRITIQUE, capteurs incohérents, capot dangereux, A15, lavage inefficace, retour courant après coupure et perte sonde température persistante. | Should | Tranchée |
| B-021 | Choisir pour le MVP une plateforme définitive compatible Wi-Fi V2 sans remplacement matériel principal ; Ethernet non requis, BLE seul insuffisant et SMS non retenu par défaut. | Must | Tranchée |
| B-023 | Définir le test journalier automatique V1.1 avec fenêtre configurable par défaut 11h-15h, report automatique si sécurité active, capot ouvert, EP_CRITIQUE, lavage en cours ou alarme bloquante, puis critères de succès et diagnostic attendu. | Should | Tranchée |
| B-024 | Retenir pour V1.1 une indexation tambour au temps, par courte rotation configurable après certains lavages réussis ou périodiquement, sans angle précis tant qu'aucun capteur position n'est retenu. | Should | Tranchée |
| B-025 | Définir les statistiques de lavage V1.1 en separant lavages automatiques réussis, tests, échecs et interruptions ; restitution locale simple : compteurs jour, dernier lavage et nombre d'échecs. | Should | Tranchée |
| B-026 | Retenir l'indice expérimental stable `lavages par heure x duree moyenne lavage`, sans action automatique ; alerte future seulement sur dérive relative après observation. | Should | Tranchée |
| B-027 | Estimer la consommation d'eau par `debit mesure aux buses x durée de rinçage cumulee`, avec pertes évacuation et besoin de remplissage indicatifs sans compteur d'eau dédié. | Should | Tranchée |
| B-028 | Retenir en V1.1 des compteurs horaires cumulés simples par organe principal ; remises à zéro maintenance et seuils de rappel reportés V2. | Should | Tranchée |
| B-029 | Définir la vue synthèse de l'IHM locale avec mode actuel, état niveau, état lavage, alarme active et température eau visibles sans navigation complexe, plus priorité d'affichage des alarmes V1. | Must | Tranchée |
| B-030 | Implémenter pour une V2 la politique anti-spam des notifications immédiates : apparition, rappel rare si toujours actif et retour à la normale pour les alarmes importantes. | Should | Tranchée |
| B-031 | Implémenter pour une V2 Wi-Fi une synthèse quotidienne désactivée par défaut, configurable, envoyee à 18h00 par défaut si activée, sur le même canal que les notifications immédiates. | Should | Tranchée |
| B-032 | Implémenter le pilotage horaire pompe décoration V1.1/V2 avec deux plages maximum par jour, mêmes horaires tous les jours, interrupteur actif/inactif et priorité sécurités, manuel local, distant, horaire. | Should | Tranchée |
| B-033 | Figer le nommage et l'ordre physique des capteurs EP_LAVAGE et EP_CRITIQUE ainsi que les règles d'incohérence associées, notamment EP_CRITIQUE actif avec EP_LAVAGE inactif comme défaut bloquant. | Must | En cours |
| B-034 | Définir la taxonomie finale des alarmes indirectes, leurs codes `Axx - MESSAGE COURT` et leurs formulations utilisateur non ambigues, dont A01 à A15 V1. | Must | Tranchée |
| B-035 | Documenter que rotation tambour, courant mesuré, fuite local et niveau eau sale restent hors diagnostic direct V1 faute de capteurs dedies ; les diagnostics logiciels restent basés sur effets observés. | Must | Tranchée |
| B-036 | Documenter que la pompe décoration suit les mêmes sécurités que la filtration car elle aspire au même endroit. | Must | Tranchée |
| B-037 | Prévoir une protection matérielle obligatoire contre la surintensité ou le blocage du moteur tambour ; remonter l'information à l'automate seulement si le module choisi le permet simplement. | Must | Tranchée |
| B-038 | Ne pas dépendre d'une fonction de parking ou de position moteur en V1 ; garder l'indexation au temps en V1.1 sauf ajout futur d'un capteur de position. | Should | Tranchée |
| B-039 | Mesurer le débit de rinçage de référence sur les buses et la rampe déjà fabriquées après montage réel de la pompe et prise en compte des pertes de charge ; utiliser la courbe pompe seulement comme estimation provisoire. | Must | Tranchée |
| B-040 | Ne pas ajouter de pressostat, débitmètre ou retour courant pour diagnostiquer le rinçage en V1 ; reporter ces capteurs V1.1/V2 si les essais montrent trop d'ambiguite. | Should | Tranchée |
| B-041 | Integrer au choix de plateforme V1 la capacité d'heure fiable V2 sans remplacement matériel principal, par RTC DS3231 I2C 3,3 V avec batterie rechargeable, synchronisation réseau seulement en complement, sans dépendance exclusive à Internet. | Must | Tranchée |
| B-042 | Retenir l'UV hors tambour, après la pompe principale, asservi a filtration autorisée plus absence EP_CRITIQUE, sans coupure sur défaut FAT non critique. | Must | Tranchée |
| B-043 | Retenir en tete de tableau un interrupteur differentiel 2P 30 mA, 40 A, type A, coherent avec les charges reelles du MVP et la notice AquaForte DM-Vario qui demande 30 mA sans imposer type F ou B. | Must | Tranchée |
| B-044 | Retenir une distribution 230 VAC avec departs : 4 A courbe C alimentation 12 V, 6 A courbe C pompe rincage, 16 A courbe C prises local, 6 A courbe C pompe filtration, 6 A courbe C UV/pompe decoration/mise a niveau, 6 A courbe C eclairage exterieur. | Must | Tranchée |
| B-045 | Retenir une distribution 12 VDC Mean Well NDR-120-12 + porte-fusibles ATO 4 departs : moteur 5 A, automate 3 A, capteurs/boutons 1 A, ecran/voyants/accessoires 1 A. | Must | Tranchée |
| B-046 | Statuer avant gel de la conception sur le comportement du système en restriction d'eau / canicule : autorisation ou inhibition explicite de la mise à niveau automatique et des lavages, information opérateur, maintien impératif de l'aération, seuils de surveillance et conduite à tenir avant `EP_CRITIQUE`. | Must | À faire |

## FAT existant a finaliser

| ID | Element | Priorité | Statut |
| --- | --- | --- | --- |
| B-050 | Réaliser les ouvertures dans le tuyau servant de tambour après validation du calcul de surface utile. | Must | À faire |
| B-051 | Poser la maille inox autour du tambour. | Must | À faire |
| B-052 | Raccorder la rampe d'aspersion de 32 mm déjà fabriquée à la pompe de rinçage. | Must | À faire |
| B-053 | Percer la prise d'eau de la pompe de rinçage sur une paroi du filtre. | Must | À faire |
| B-054 | Percer et equiper la vidange du filtre. | Must | À faire |
| B-055 | Poser le joint a levre de séparation eau propre / eau sale autour du tambour. | Must | À faire |
| B-056 | Fabriquer le support du FAT pour respecter la cote de trop-plein mesurée sur site. | Must | À faire |
| B-057 | Fixer les capteurs sur le report de niveau en 32 mm. | Must | À faire |
| B-058 | Réaliser le capot transparent de fermeture avec détection d'ouverture par fin de course OMRCH ME-8104, permettant de voir le tambour tourner sans ouvrir le FAT. | Must | À faire |
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

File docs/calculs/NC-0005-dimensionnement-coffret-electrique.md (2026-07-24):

# NC-0005 - Dimensionnement du coffret electrique

## Objet

Cette note dimensionne le coffret electrique du controleur FAT V1 a partir des
equipements actuellement retenus. Elle fixe :

- la matiere du coffret pour ne pas degrader le Wi-Fi de la KC868-A16 ;
- le nombre d'emplacements equivalents sur rail DIN ;
- une implantation de principe separant le 230 VAC et la basse tension ;
- une dimension minimale et une dimension recommandee avant achat.

Un emplacement modulaire est compte sur une largeur de **18 mm**. Les appareils
industriels qui ne suivent pas exactement ce pas sont arrondis a l'emplacement
superieur. Ce bilan sert au choix du coffret, mais ne remplace pas le schema
electrique, la verification des distances constructeur ni la revue 230 VAC par
une personne competente.

## Contraintes d'entree

- Coffret installe dans un local technique humide, avec condensation et
  projections possibles : **IP65 cible**.
- Enveloppe **imperativement non metallique** pour le Wi-Fi : polyester renforce,
  polycarbonate ou ABS industriel adapte a l'environnement.
- KC868-A16 REV.1.6.3 : boitier annonce a `186 x 106 mm`, soit 10,33 modules de
  largeur, comptes **11 emplacements**.
- Porte-fusibles ATO sur support imprime 3D : **3 emplacements**, valeur fournie
  par la CAO.
- Relais HELLA sur support imprime 3D : **2 emplacements**, valeur fournie par la
  CAO.
- Alimentation Mean Well NDR-120-12 : largeur 40 mm, soit 2,22 modules, comptes
  **3 emplacements**. Le constructeur recommande aussi 40 mm libres au-dessus,
  20 mm au-dessous, 5 mm sur les cotes, ou 15 mm vis-a-vis d'une source chaude.
- Contacteur Schneider LC1D18P7 : largeur 45 mm, soit 2,5 modules, comptes
  **3 emplacements**.
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

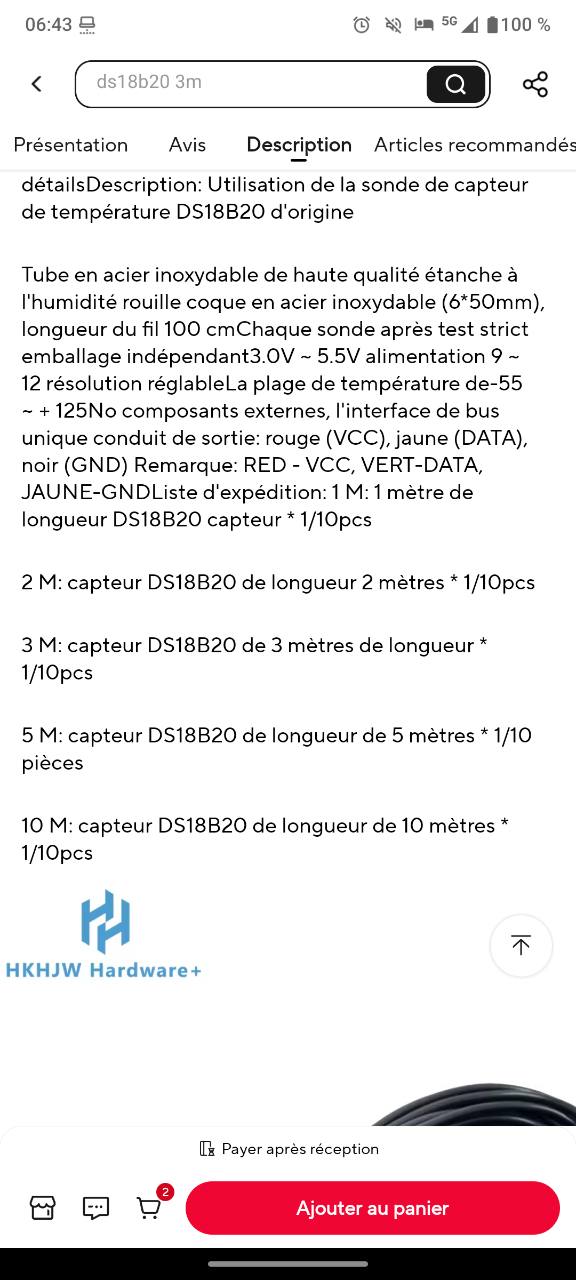
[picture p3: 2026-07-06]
.codex-remote-attachments/019f33f1-c05f-7f91-af10-d79935c81f97/cc94f98a-e4e9-46e8-ad8d-94998c7d9280/1-Photo-1.jpg

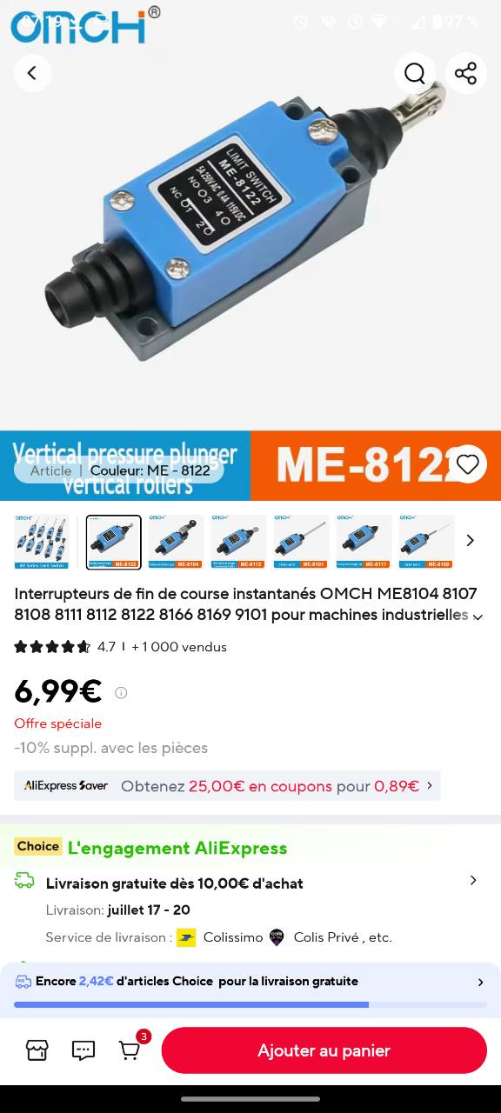
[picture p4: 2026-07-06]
.codex-remote-attachments/019f33f1-c05f-7f91-af10-d79935c81f97/20843a0d-a55b-48ef-9e52-5f747c4e6500/1-Photo-1.jpg

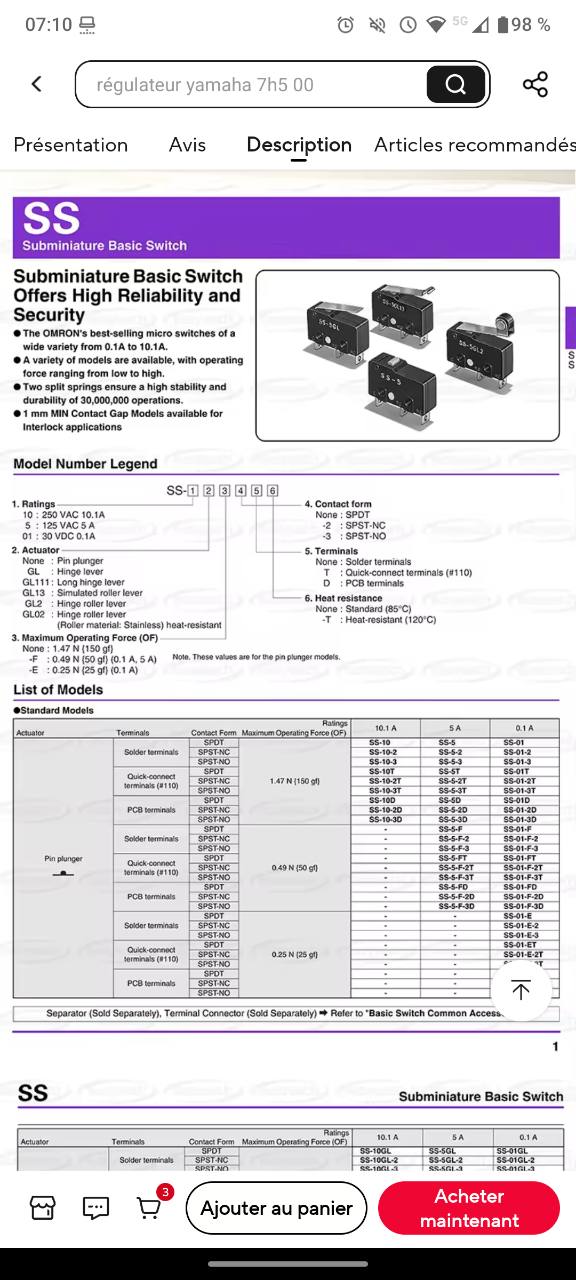
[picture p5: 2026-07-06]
.codex-remote-attachments/019f33f1-c05f-7f91-af10-d79935c81f97/10ab2783-30c6-4e73-9794-46f6ccbc6154/1-Photo-1.jpg

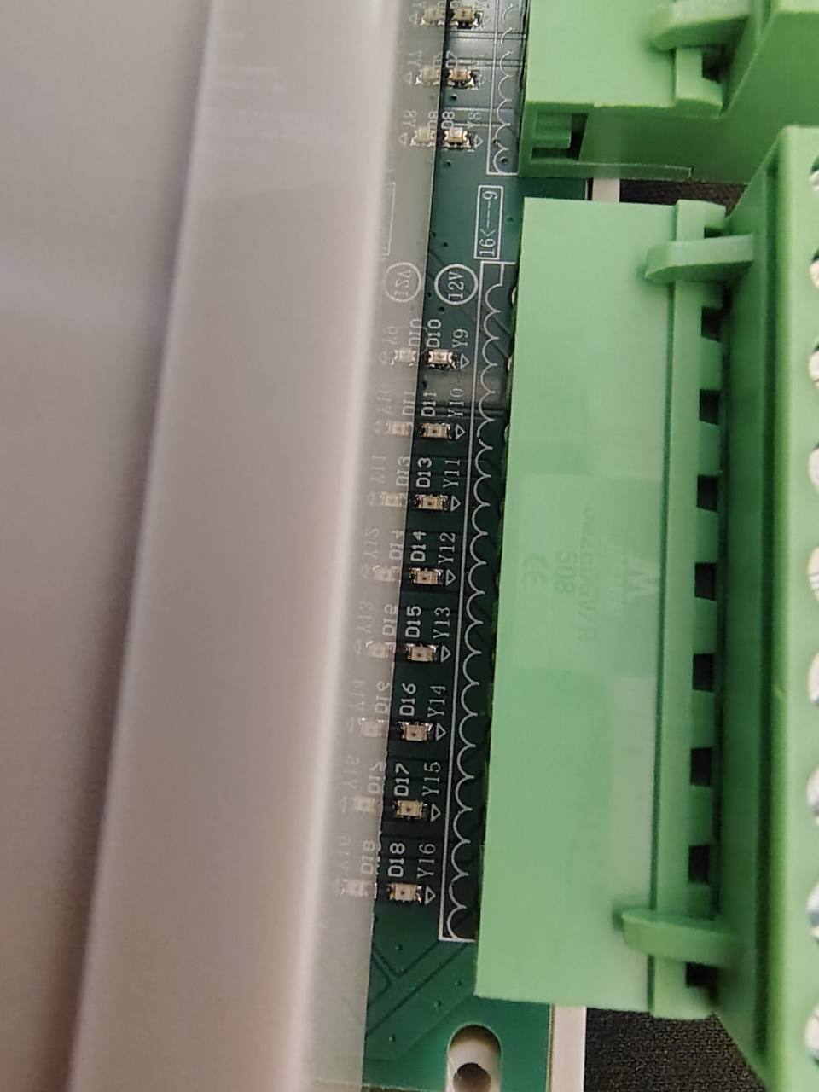
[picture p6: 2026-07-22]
.codex-remote-attachments/019f6168-8cca-70a1-9c1a-e4df0d75bf8c/f56a9f00-87c8-4bf0-b8bb-db82c01a47da/1-Photo-1.jpg

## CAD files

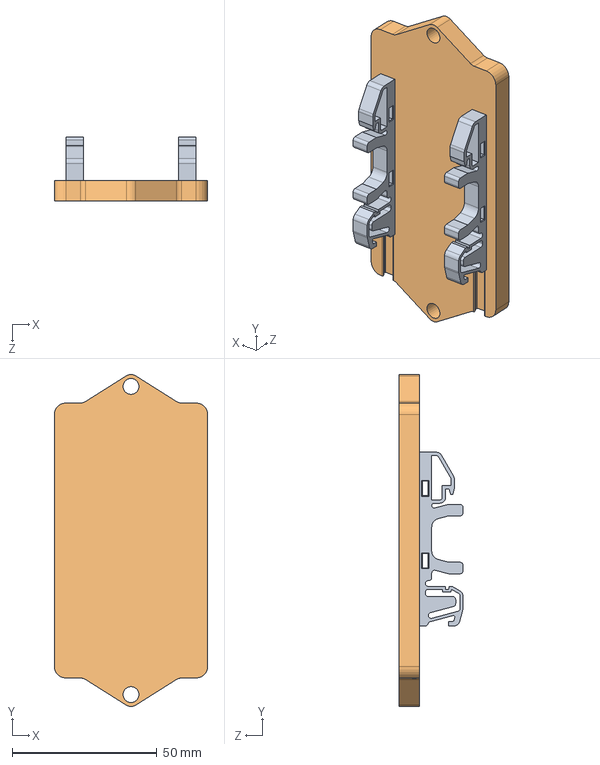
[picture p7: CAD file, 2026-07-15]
3D/test_assemblage_porte_fusible.SLDASM
53.0 x 114.7 x 22.1 mm
porte_fusible
support_DIN_tenon x 2

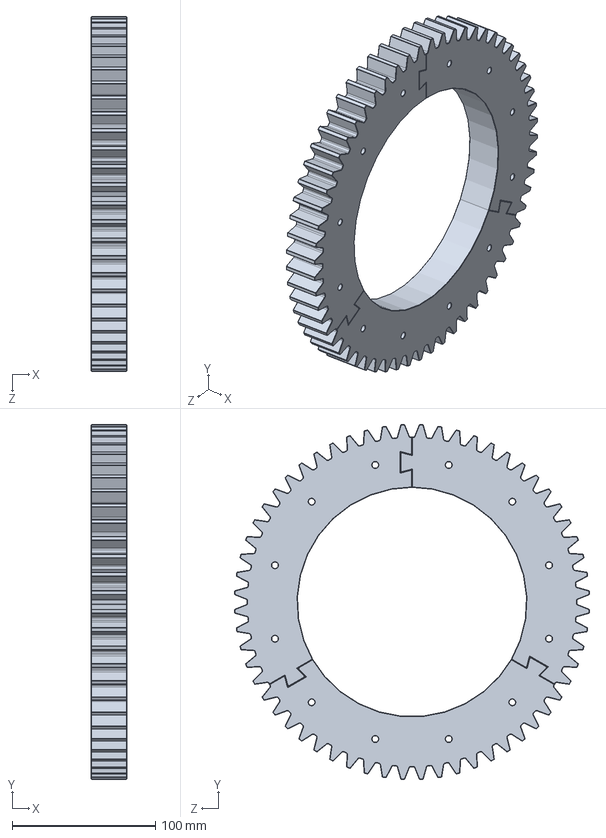
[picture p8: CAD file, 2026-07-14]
3D/couronne_assemblée.SLDASM
25.0 x 247.8 x 247.8 mm
couronne_partie x 3

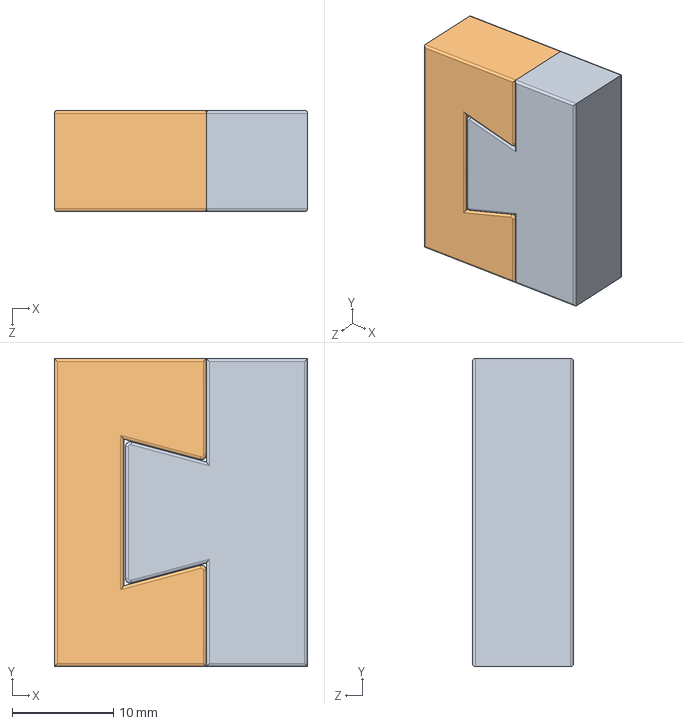
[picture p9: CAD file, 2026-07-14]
3D/test_aronde.SLDASM
25.0 x 30.4 x 10.0 mm
test_mortaise_aronde
test_tenon_aronde

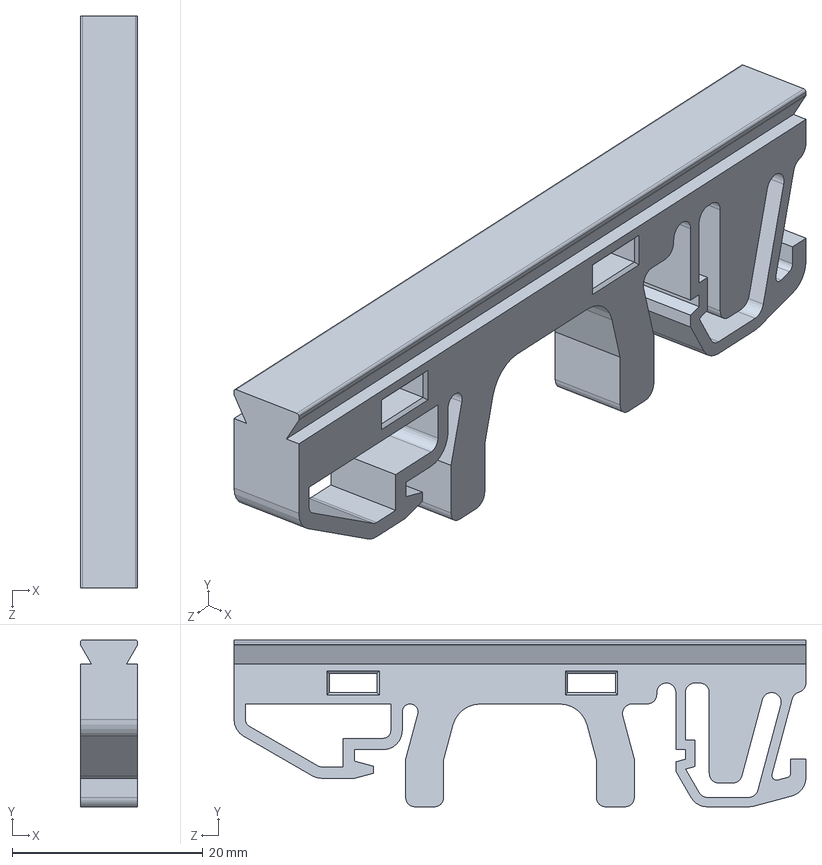
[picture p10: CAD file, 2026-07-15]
3D/support_DIN_tenon.SLDPRT
6.00 x 17.5 x 60.0 mm

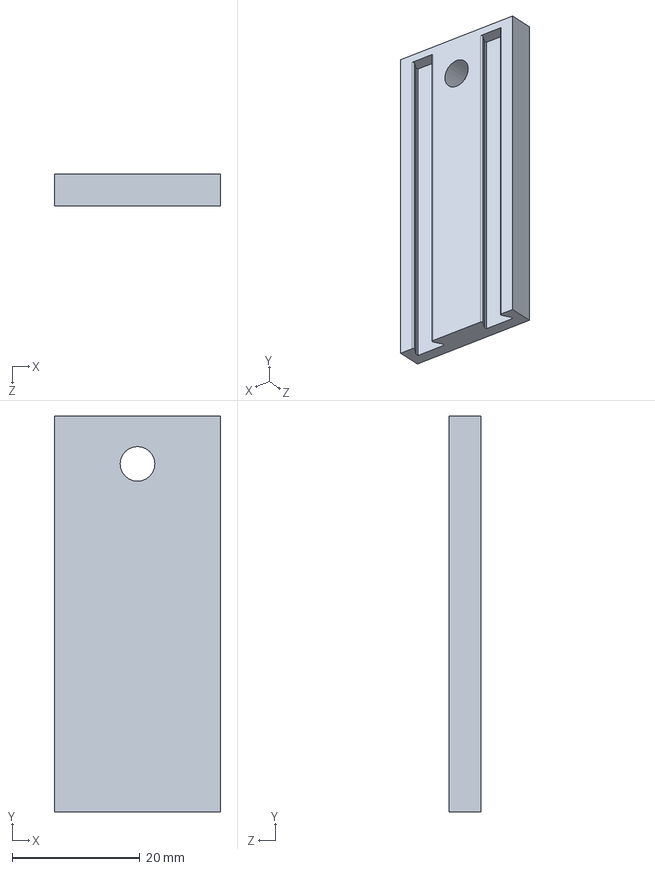
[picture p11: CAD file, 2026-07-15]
3D/porte_relais.SLDPRT
26.0 x 62.0 x 5.00 mm

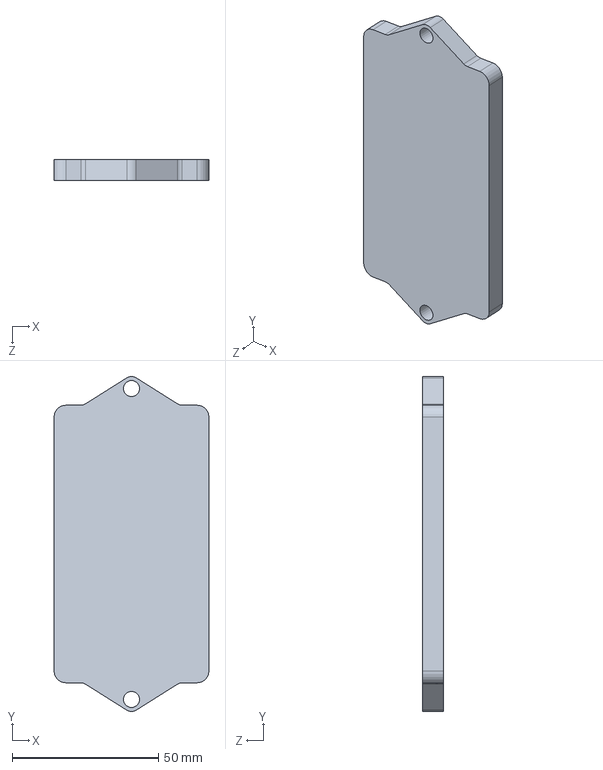
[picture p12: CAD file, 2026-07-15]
3D/porte_fusible.SLDPRT
53.0 x 114.7 x 7.10 mm

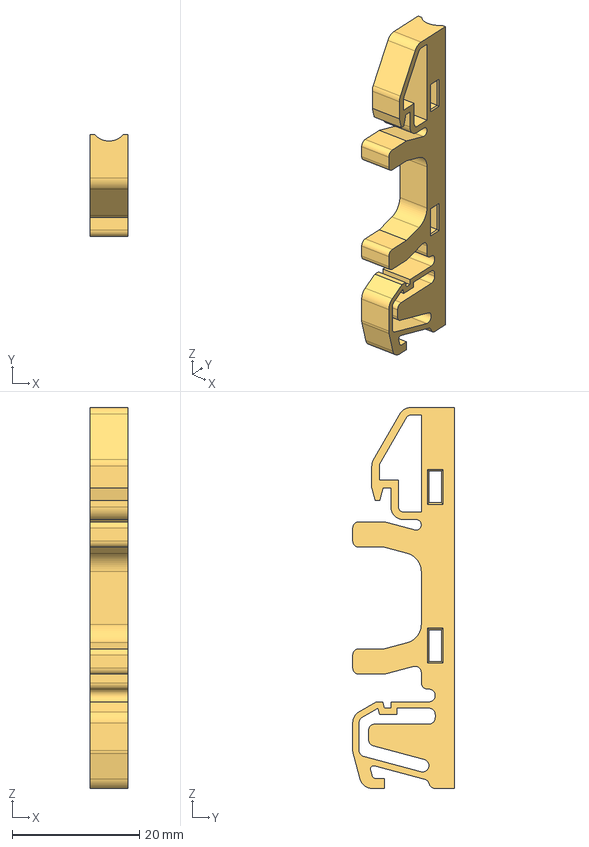
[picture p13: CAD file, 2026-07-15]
3D/DIN_Rail_Cable_Clamp.step
6.00 x 16.0 x 60.0 mm

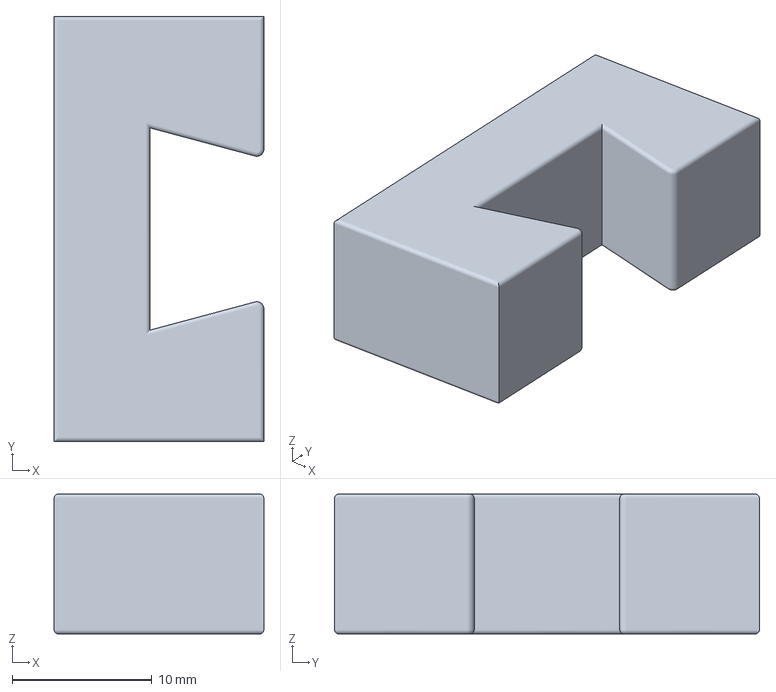
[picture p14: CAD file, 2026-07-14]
3D/test_mortaise_aronde2.3MF
15.0 x 30.4 x 10.0 mm

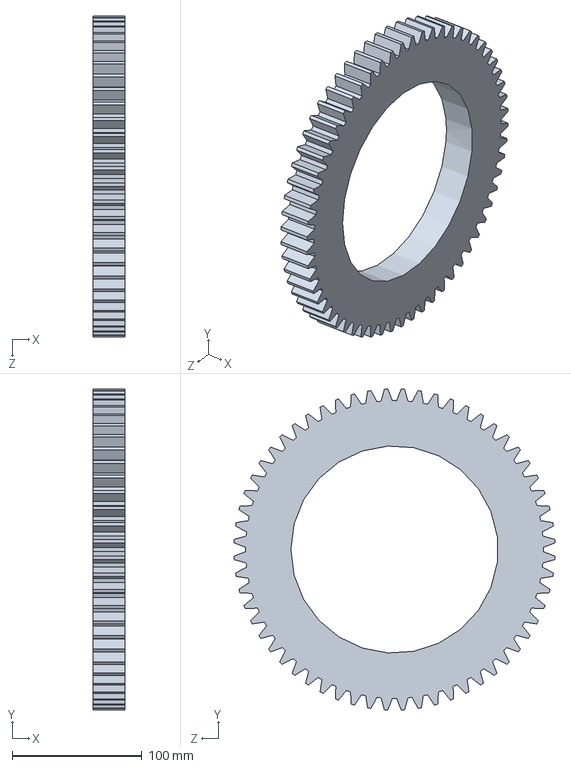
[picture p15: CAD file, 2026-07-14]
3D/pignon.SLDPRT
25.0 x 247.8 x 247.8 mm

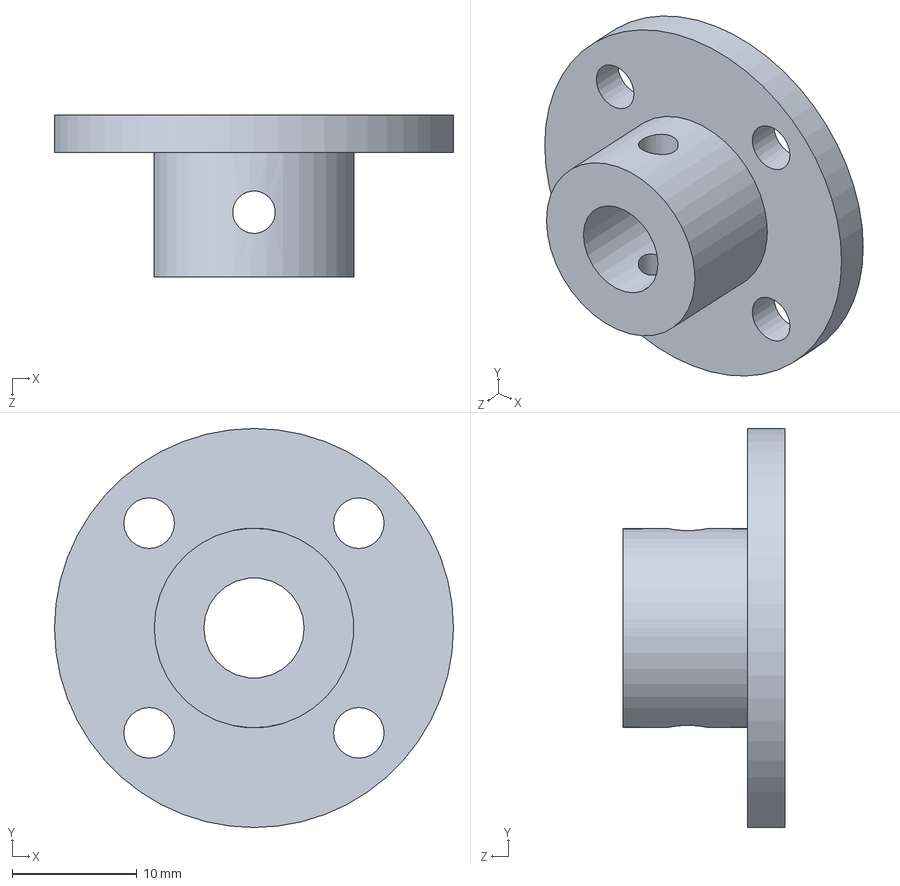
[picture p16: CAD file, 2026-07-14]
3D/moyeu_moteur_tambour.SLDPRT
32.0 x 32.0 x 13.0 mm

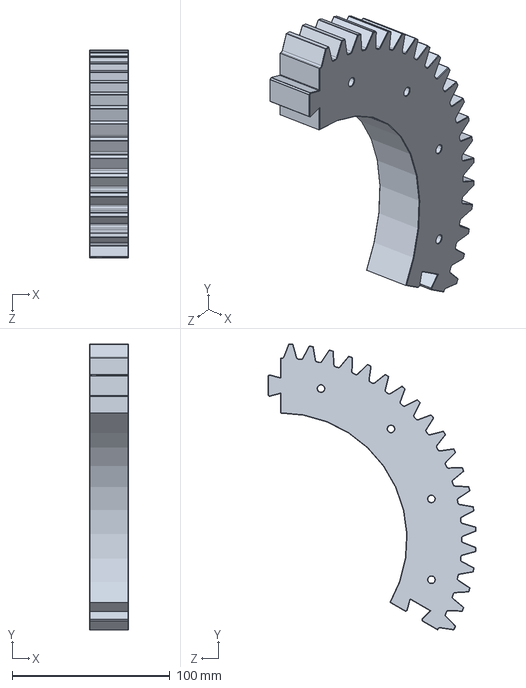
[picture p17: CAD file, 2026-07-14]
3D/couronne_partie.SLDPRT
25.0 x 181.4 x 131.9 mm

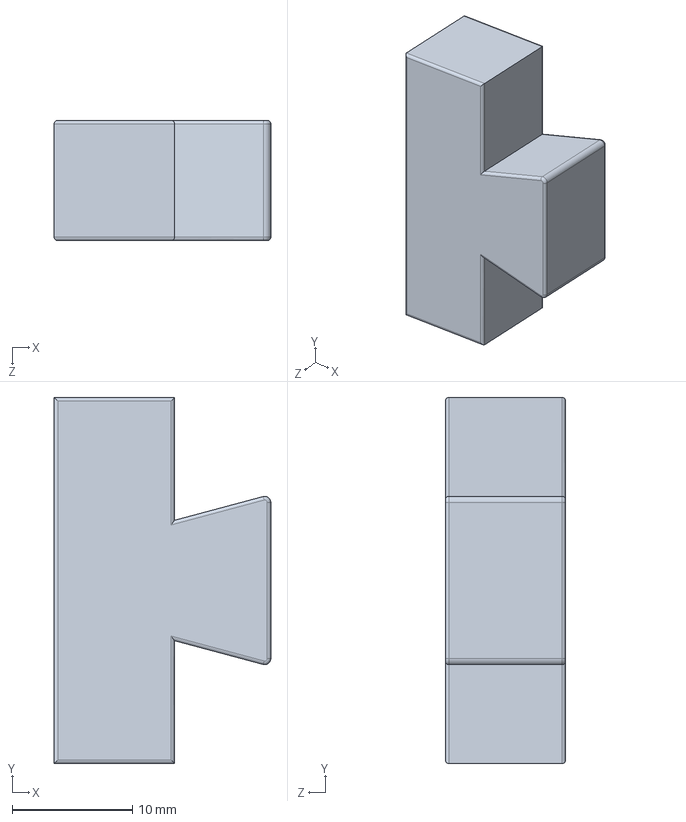
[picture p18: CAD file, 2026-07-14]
3D/test_tenon_aronde.SLDPRT
18.0 x 30.4 x 10.0 mm

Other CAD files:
3D/engrenages.SLDASM
3D/test_mortaise_aronde.SLDPRT
3D/couronne_partie.3mf
3D/porte_fusible.3mf
3D/porte_relais.3mf
3D/support_DIN_tenon.3mf
3D/test_mortaise_aronde.3mf
3D/test_tenon_aronde.3MF

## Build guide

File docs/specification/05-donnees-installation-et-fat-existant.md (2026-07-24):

# Données d'entrée de l'installation et FAT existant

## Vue d'ensemble

Le projet porte sur un filtre à tambour (FAT) deja partiellement construit et intégré dans une ligne de filtration de bassin. Les dimensions et interfaces ci-dessous sont considerees comme des caractéristiques d'entrée stables pour la conception mécanique, hydraulique et de pilotage.

## Environnement d'installation

Le FAT sera installe dans un local de filtration maconne, isole avec 5 cm de XPS. Un capot transparent relevable sera present au-dessus du petit batiment afin de voir le tambour tourner sans ouvrir le FAT. Le capot et le couvercle transparent désignent la même pièce physique. Sa matiere et son niveau d'isolation restent à définir.

Le FAT ne sera donc pas expose à la pluie directe. L'environnement reste toutefois un local de filtration humide, avec risque de condensation, projections ponctuelles et contraintes de maintenance.

Le coffret électrique doit être adapté à ce local humide : minimum IP55, préférence IP65, presse-étoupes adaptés, séparation propre entre basse tension et 230 VAC, réserve de place et gestion de condensation si nécessaire. Il ne doit pas être installé sous une zone de ruissellement ou de projection directe.

Le capteur de température ambiante local doit mesurer l'air du local de filtration. Il sera placé hors coffret, dans une zone ventilée et accessible, à distance de l'alimentation, des contacteurs, des pompes, du soleil et du volume sous capot si celui-ci crée une stratification thermique.

## Géométrie immuable du FAT

### Enveloppe générale

| Element | Valeur | Notes |
| --- | --- | --- |
| Surface totale eau propre + eau sale | 78 cm x 47 cm | Surface interne totale du filtre |
| Hauteur d'eau maximale avant debordement | 30,5 cm | Au-delà, l'eau deborde dans la goutiere d'évacuation |
| Volume géométrique théorique total jusqu'au trop-plein | 111,8 L | Calcul: 78 x 47 x 30,5 cm |

### Partie eau propre

| Element | Valeur | Notes |
| --- | --- | --- |
| Compartiment eau propre | 62 cm x 47 cm x 30,5 cm max | Volume géométrique théorique: 88,9 L |
| Tambour | diamètre 31 cm x longueur 57 cm | Longueur utile côté eau propre |
| Volume géométrique du cylindre de tambour | 42,9 L | Valeur utile pour l'encombrement, pas pour estimer a elle seule le volume d'eau libre |

### Partie eau sale

| Element | Valeur | Notes |
| --- | --- | --- |
| Largeur théorique résiduelle | 16 cm | Difference entre 78 cm et 62 cm |
| Surface théorique résiduelle | 16 cm x 47 cm | À confirmer sur plan si des cloisons locales modifient cette section |
| Volume géométrique théorique jusqu'au trop-plein | 22,9 L | Calcul sur la section résiduelle |

## Hypothèse hydraulique de travail sur le niveau côté sale

| Element | Valeur | Notes |
| --- | --- | --- |
| Niveau d'eau sale nominal vise | environ 20 cm au-dessus du bas du tambour | Hypothèse de travail à confirmer sur installation |
| Position du bas du tambour | 7 cm au-dessus du fond du filtre | Donnée fournie |
| Niveau d'eau correspondant depuis le fond du filtre | environ 27 cm | 7 cm + 20 cm |
| Marge sous le trop-plein | environ 3,5 cm | Avec trop-plein fixe à 30,5 cm |

### Conséquences estimées sur l'immersion du tambour

| Element | Valeur | Notes |
| --- | --- | --- |
| Hauteur d'eau sur le tambour | environ 20 cm | Soit environ 64,5 % du diamètre 31 cm en hauteur verticale |
| Circonference totale du tambour | environ 97,4 cm | Calcul à partir du diamètre 31 cm |
| Surface totale de toile du tambour | environ 0,55 m2 | Circonference x longueur 57 cm |
| Part de circonference immergée | environ 59 % | Soit une longueur developpee immergée d'environ 58 cm |
| Surface de toile immergée brute | environ 0,33 m2 | Sur environ 0,55 m2 de toile totale |
| Surface filtrante utile visee | environ 0,20 à 0,23 m2 | Selon la geometrie réelle des ouvertures et le taux de passage utile |

## Interfaces hydrauliques connues

| Interface | Valeur | Notes |
| --- | --- | --- |
| Arrivee eau sale | 2 entrées de 110 mm | Bonde de fond + skimmer en gravitaire |
| Sortie eau propre | 2 sorties de 110 mm | Maintien du flux hydraulique vers la filtration bio |
| Goutiere d'évacuation | trop-plein à 30,5 cm | Goutiere fixe avec legere pente |
| Évacuation des dechets rinces | tuyau de 100 mm | Place en sortie de goutiere |
| Report de niveau eau propre | tuyau de 32 mm | Support de fixation des capteurs de niveau |
| Mise à l'air du report de niveau | trou de 1 mm dans le bouchon | Le bouchon haut reste demontable pour nettoyage |
| Rampe d'aspersion | tuyau de 32 mm + buses | Déjà achetés et fabriqués ; à raccorder à la pompe de rinçage |

## Composants deja retenus

### Filtration mécanique

| Element | Valeur | Notes |
| --- | --- | --- |
| Toile de filtration | inox 74 microns | Maille de filtration retenue pour le tambour |

### Capteurs de niveau

| Element | Valeur | Notes |
| --- | --- | --- |
| Référence capteur | CR18-8DN | Capteur de niveau retenu |
| Format mécanique | M18 | A prendre en compte pour le support sur tube de report |
| Distance de détection ajustable | 8 mm | Valeur fournie |
| Sortie | NPN normalement ouverte | Sortie collecteur ouvert compatible en premiere intention avec une entrée KC868-A16 activée par tirage vers 0 V |
| Alimentation | 12-24 VDC, plage admissible 10-30 VDC | Alimentation V1 retenue en 12 VDC |
| Consommation | 10 mA max | Valeur unitaire fournie |
| Courant de sortie | 200 mA max | Marge probablement suffisante ; courant reel de l'entree optocouplee KC868-A16 a mesurer sur la revision recue |
| Câblage | DC 3 fils | Marron `+12 VDC`, bleu `0 V`, noir vers entrée digitale KC868-A16 |
| Protection capteur | IP65 | Adapté aux projections, pas à une immersion ou un lavage haute pression |

Le MVP retient deux capteurs câblés sur le tube de report eau propre : EP_LAVAGE au-dessus de EP_CRITIQUE. Les supports doivent être réglables en hauteur afin de caler les seuils après mesure du niveau normal réel. Une réserve mécanique non câblée peut être prévue pour un troisième capteur futur si les essais le justifient.

L'interface électrique retenue en premiere intention est un raccordement direct sur les entrées digitales optocouplées de la KC868-A16, prévues pour une activation vers `GND`. Le CR18-8DN NPN est donc raccorde comme un contact électronique vers 0 V, sans relais d'interface par défaut. La validation finale se fait sur banc avec la revision A16 et les vrais capteurs, notamment courant d'entree, sens logique, stabilité, rupture de fil et longueurs de câble réelles.

### Motorisation tambour

| Element | Valeur | Notes |
| --- | --- | --- |
| Moteur retenu | Motorreducteur Fyearfly 12 VDC 10 rpm | Remplace le candidat initial de moteur d'essuie-glace |
| Tension moteur | 12 V DC | Alimente par le rail 12 VDC V1 |
| Vitesse retenue | 10 rpm en sortie motorreducteur | Vitesse finale tambour a valider avec la transmission réelle |
| Couple nominal annonce | 70 kg.cm, soit environ 6,9 N.m | Donnee fournisseur issue de la capture produit transmise, a confirmer sur montage reel |
| Couple maximal annonce | 70 kg.cm, soit environ 6,9 N.m | Valeur identique au couple nominal dans la capture ; a traiter avec prudence |
| Courant nominal annonce | < 1,6 A selon capture produit | Donnee a confirmer par mesure sur montage réel |
| Courant de blocage / d'arret annonce | 6,5 A selon screenshot fournisseur transmis | Sert d'ordre de grandeur pour choisir une protection plus restrictive ; comportement reel du fusible 5 A a confirmer par test |
| Fusible retenu | ATO 5 A | Depart 12 VDC moteur tambour |
| Relais retenu | HELLA 4RD 933 332-551, 12 V, charge inductive 15 A | Relais de puissance moteur, support rail DIN a imprimer en 3D |
| Couple moteur réel | Non mesure | Donnée critique à valider par essais malgré le couple fournisseur annonce |
| Usage retenu | Intermittent pendant les cycles de lavage | Usage continu 24/24 non recommandé |

La transmission exacte autour du motorreducteur 10 rpm reste a finaliser. Le choix du Fyearfly rend caduque l'hypothèse initiale de moteur d'essuie-glace a 95 tr/min avec réduction 3:1, qui donnait une vitesse tambour probablement trop élevée.

Le moteur doit rester hors eau et protège des projections. Le courant de blocage annoncé de 6,5 A permet de pré-dimensionner la protection moteur du MVP. Le couple fournisseur annonce de 70 kg.cm, soit environ 6,9 N.m, donne un ordre de grandeur utile pour la transmission, mais ne remplace pas les mesures sur le tambour reel. La vitesse finale, le courant en charge, le couple disponible, la fixation mécanique et le comportement réel en blocage doivent être valides avant cablage final. Le détail du dimensionnement est tracé dans [../calculs/NC-0002-dimensionnement-motorisation-tambour.md](../calculs/NC-0002-dimensionnement-motorisation-tambour.md).

Hypothèse de transmission mécanique en cours de conception : engrenages droits PETG module 4, angle de pression 20 degres, largeur 25 mm et rapport 2:1. Le pignon moteur fait 30 dents et est monté sur un moyeu aluminium pour arbre en D 8 mm ; la couronne tambour fait 60 dents, avec alesage central diametre 160 mm, et est imprimée en 3 segments de 120 degres. Chaque segment est vissé sur la plaque latérale par 4 vis M4 sur un cercle de percage diametre 198 mm, avec rondelles larges diametre 12 mm et alignement par queues d'aronde axiales. Cette géométrie donne environ 5 tr/min au tambour, soit environ 8,1 cm/s en vitesse périphérique et environ 12 s par tour complet. L'entraxe théorique est de 180 mm ; le support moteur doit permettre son réglage autour de cette valeur. Le détail de fabrication et les paramètres d'impression sont tracés dans la note NC-0002.

### Architecture electrique V1

| Element | Valeur | Notes |
| --- | --- | --- |
| Protection amont cote maison | Disjoncteur dedie 16 A | Liaison existante d'environ 20 m confirmee en 3G2,5 mm2, actuellement en attente sans disjoncteur au tableau maison. Ajouter la protection 16 A avant raccordement ; le TeSys VCDN20 20 A reste utilise comme sectionneur local, pas comme protection. |
| Sequence d'alimentation cible | Disjoncteur 16 A maison -> TeSys VCDN20 -> interrupteur differentiel 30 mA -> disjoncteurs departs | Le sectionneur est la coupure locale cadenassable du coffret, avant le differentiel local |
| Tete de tableau | Interrupteur differentiel 2P 30 mA, 40 A, type A | Choix coherent avec les charges reelles du MVP ; la notice AquaForte DM-Vario demande 30 mA sans imposer type F ou B |
| Coupure locale cadenassable | Schneider Electric TeSys VCDN20, interrupteur-sectionneur 3P 690 V 20 A, poignee rouge cadenassable | Piece trouvee en atelier, candidate pour la coupure/consignation du coffret FAT, placee avant l'interrupteur differentiel local. Ne remplace pas le differentiel ni les disjoncteurs ; verifier etat, montage, coupure phase/neutre, calibre amont 16 A et maintien des bulleurs hors coupure automatique |
| Alimentation 12 VDC | Mean Well NDR-120-12, 120 W, 10 A, rail DIN | Protegee par disjoncteur 4 A courbe C |
| Distribution 12 VDC | Porte-fusibles ATO 4 emplacements | Depart moteur 5 A, automate 3 A, capteurs/boutons 1 A, ecran/voyants/accessoires 1 A ; adaptateur rail DIN imprime en 3D probable selon modele retenu |
| Plateforme controle | KC868-A16 ESP32 classique | Base automate V1/V2 selon ADR-0012 ; 16 entrees et 16 sorties MOSFET 12/24 VDC |
| Ecran local | LCD 2004 / 20x4 I2C 3,3 V, fond bleu | Raccordement cible sur KC868-A16 via `GPIO32` / `GPIO33` et un bus I2C auxiliaire separe ; validation banc requise avant cablage final |
| Horloge temps reel | Module RTC DS3231 I2C 3,3 V avec batterie rechargeable | Source locale d'heure fiable V2 ; adresse attendue `0x68`, raccordement cible sur le bus I2C auxiliaire KC868-A16 si cohabitation validee avec le LCD 2004 |
| Pompe rincage | Disjoncteur 6 A courbe C + contacteur Schneider TeSys LC1D18P7, bobine 230 VAC | Courant nominal pompe 3,5 A. La courbe C absorbe l'appel de demarrage ; 6 A remplace 10 A pour une protection plus ajustee du depart. La bobine est pilotee par un relais d'interface commande par l'automate, avec separation BT/secteur et reperage a traiter au schema final. |
| Prises local | Disjoncteur 16 A courbe C | 1 prise bulleur bassin, 1 prise bulleur filtre bio, 2 prises maintenance ponctuelle ; le courant total du coffret reste limite par le disjoncteur amont 16 A cote maison |
| Pompe filtration | Disjoncteur 6 A courbe C + contacteur TOMZN TOCT1-25Z 25 A, bobine 12 VDC | Depart separe car organe essentiel |
| UV, pompe decoration, mise a niveau | Disjoncteur 6 A courbe C + contacteurs TOMZN TOCT1-25Z 25 A, bobine 12 VDC | Separés du depart filtration |
| Eclairage exterieur | Disjoncteur 6 A courbe C | Depart supplementaire dans le coffret pour 6 spots LED exterieurs de 3 W avec detecteurs, environ 10 a 15 m de cable. Circuit hors fonctions bassin, sans commande ni securite FAT |

### Sections de cable retenues pour le cablage MVP

| Liaison | Section retenue | Notes |
| --- | --- | --- |
| Moteur tambour 12 VDC | 2 x 2,5 mm2 | Section retenue pour limiter la chute de tension sur le depart moteur protege par fusible ATO 5 A. |
| Voyants et boutons IHM locale | 0,5 mm2 | Section retenue pour les commandes et signalisations basse tension en facade. |
| Circuits 230 VAC cote filtration | 1,5 mm2 | Section retenue pour les departs 230 VAC locaux et le cablage interne de l'armoire ; sous reserve de verification du schema final, des conditions de pose et des protections associees. |

### Pompe de rinçage

| Element | Valeur | Notes |
| --- | --- | --- |
| Pompe retenue | VEVOR / Leo EKJ-802S | Garden Jet Pump de surface auto-amorcante |
| Fabricant OEM | Leo Group Pump (Zhejiang) Co., Ltd. | Information fournisseur |
| Numéro de serie | 221228693910166 | Donnée plaque |
| Alimentation | 220-240 VAC, 50 Hz | Pompe secteur monophase |
| Puissance | 800 W indique projet ; 0,6 kW / 0,8 HP sur fiche Leo | Divergence a garder visible pour dimensionnement prudent |
| Courant nominal fiche | 3,5 A | Le courant d'appel moteur reste à prendre en compte |
| Débit maximal | 3,6 à 3,7 m3/h, soit environ 60 L/min | Valeur de bout de courbe, pas disponible en même temps que la hauteur maximale |
| Hauteur maximale | 40 à 43 m | Selon source ; la courbe Leo indique 43 m a débit nul |
| Raccords aspiration / refoulement | 1 pouce / 1 pouce | A adaptér vers la prise d'eau et la rampe 32 mm |
| Température liquide maximale | 35 degC projet ; 40 degC fiche | Retenir 35 degC par prudence tant que la source exacte n'est pas arbitree |
| Température ambiante maximale | 40 degC | Donnée fiche technique |
| Protection | IPX4, classe I, isolation F | Pompe a mettre à la terre, non immergeable |
| Corps de pompe | AISI 304 | Donnée fiche technique |
| Dimensions / poids | environ 38 x 24 x 30 cm, 9 kg | Fiche détaillée : L 369,5 mm, W 243,5 mm, H 284 mm |

La courbe disponible donne environ 20 L/min à 34 m, 30 L/min à 28 m, 40 L/min à 21 m, 50 L/min à 12,5 m et 60 L/min à 3 m. La rampe et les buses sont déjà achetées et fabriquées ; elles font partie du matériel MVP. La courbe sert seulement d'estimation provisoire. Le débit de rinçage de référence V1 devra être mesure aux buses après montage réel de la pompe, de la rampe et des pertes de charge. Le détail du dimensionnement est tracé dans [../calculs/NC-0003-dimensionnement-pompe-rincage.md](../calculs/NC-0003-dimensionnement-pompe-rincage.md).

### Hypothèse de nommage côté eau propre

| Nom | Rôle | Notes |
| --- | --- | --- |
| EP_LAVAGE | Demande de lavage | Niveau eau propre abaisse mais pas encore critique |
| EP_CRITIQUE | Danger hydraulique et arrêt de sécurité | Niveau eau propre très bas, coeur de la protection V1 |

## Chaine de filtration autour du FAT

| Element | Valeur | Notes |
| --- | --- | --- |
| Bassin | 186 cm x 411 cm x 108 cm | Volume géométrique théorique: 8,26 m3 |
| Évacuation bassin | 1 bonde de fond 110 mm + 1 skimmer 110 mm | Fonctionnement en gravitaire vers le FAT |
| Filtration biologique | cuve IBC 1000 L avec tapis japonais | En sortie du FAT |
| Pompe de filtration principale | retour bassin en 63 mm | Fonctionnement continu vise |
| Pompe décoration | usage ponctuel | Cascade, mur d'eau, lame d'eau, etc. |
| UV | hors tambour, dans la filtration, après la pompe principale | Asservi a filtration autorisée plus absence EP_CRITIQUE ; ne pas couper sur défaut FAT non critique si la filtration reste autorisée |
| Température bassin | DS18B20 étanche inox 3 fils, longueur cible 3 m | A placer dans une eau représentative : arrivée gravitaire avant pompe/UV ou bassin en zone brassée, ombragée et accessible ; alimentation 3,3 V, pull-up 4,7 kΩ sur DATA, brochage des couleurs à vérifier |
| Température ambiante local | Même DS18B20 étanche inox 3 fils que pour le bassin, longueur cible 3 m | A placer hors coffret, dans l'air du local, en support ventilé et accessible ; choix identique pour simplifier achat, câblage, stock et firmware |

## Hypothèses hydrauliques de dimensionnement de la filtration

### Objectif de renouvellement du bassin

Le renouvellement cible de l'eau du bassin est fixe entre 1 h et 1 h 30. Avec un volume géométrique théorique de 8,26 m3, cela conduit a une plage de débit nominal visee d'environ 8 à 10 m3/h pour la filtration principale.

### Repartition cible entre bonde de fond et skimmer

| Circuit | Débit cible | Part relative | Justification |
| --- | --- | --- | --- |
| Bonde de fond | 6 à 7 m3/h | environ 75 % | Garantir au moins 6 m3/h dans la conduite de bonde de fond pour conserver une vitesse d'entrainement d'environ 0,18 m/s |
| Skimmer | 2 à 3 m3/h | environ 25 % | Compléter l'aspiration de surface sans penaliser la bonde de fond |
| Total filtration principale | 8 à 10 m3/h | 100 % | Compromis entre renouvellement du bassin, capacité du FAT et temps de passage en bio |

### Contraintes de débit sur le FAT et la biofiltration

- Le FAT existant est considere comme potentiellement sous-dimensionne en surface filtrante au-delà de 10 m3/h.
- La cuve de biofiltration ne doit pas être traversee a un débit trop eleve afin de conserver un temps de contact acceptable avec les bactéries.
- Les temps de passage théoriques actuellement retenus dans la bio sont d'environ 7,5 minutes à 8 m3/h et 6 minutes à 10 m3/h.
- La presence d'une deuxième pompe de décoration ou d'usage ponctuel est susceptible de modifier les equilibres hydrauliques globaux et devra être prise en compte lors des reglages finaux.

### Conséquence pour le dimensionnement de la pompe principale

Le point de fonctionnement nominal recherche reste 8 à 10 m3/h, mais la pompe principale devra conserver une marge suffisante pour absorber les pertes de charge réelles de l'installation, rester réglable finement et éviter un fonctionnement permanent à pleine vitesse. Les calculs et la decision associés sont tracés dans [../calculs/NC-0001-dimensionnement-pompe-filtration.md](../calculs/NC-0001-dimensionnement-pompe-filtration.md) et [../decisions/ADR-0002-dimensionnement-pompe-filtration-principale.md](../decisions/ADR-0002-dimensionnement-pompe-filtration-principale.md).

## Hypothèses de conception à retenir

- Le seuil physique de debordement du filtre est impose par la goutiere à 30,5 cm au-dessus du fond du filtre.
- La logique de pilotage V1 repose sur une cote simple côté eau propre, avec deux niveaux fonctionnels : EP_LAVAGE et EP_CRITIQUE.
- Les capteurs de niveau doivent être positionnes côté eau propre sur le tube de report en 32 mm, et non directement dans la zone sale.
- EP_LAVAGE est placé physiquement au-dessus de EP_CRITIQUE, les deux sur supports réglables en hauteur ; une réserve mécanique pour un troisième capteur futur peut être prévue sans câblage MVP.
- Les capteurs de niveau retenus sont des CR18-8DN en M18, sortie NPN, alimentation 12-24 VDC, câblage 3 fils.
- Le moteur tambour retenu est un motorreducteur Fyearfly 12 VDC 10 rpm, en fonctionnement intermittent.
- L'alimentation moteur et le fusible 5 A sont pré-dimensionnés en tenant compte du courant de blocage annoncé de 6,5 A ; le calibre 5 A est retenu pour essai afin d'etre plus protecteur que l'hypothese 7,5 A, mais il doit etre confirme par mesure du courant réel au démarrage, en charge et en blocage.
- Une protection contre blocage ou surintensité du moteur tambour doit être prévue ou fortement justifiée si elle est absente.
- La pompe de rinçage retenue est une pompe de surface VEVOR / Leo EKJ-802S en 220-240 VAC ; elle doit être commandée comme une charge moteur secteur.
- La pompe de rinçage est commandée par un contacteur Schneider TeSys LC1D18P7, bobine 230 VAC, lui-même piloté directement par un relais de l'automate ; cette reference remplace le LC1D12P7 car elle conserve la meme bobine de commande tout en apportant une marge AC-3 superieure. Le relais intermediaire 12 V -> 230 V n'est pas retenu afin d'eviter une architecture trop complexe, et le contacteur equivalent en bobine 12 VDC / AC-3 est considere difficile a sourcer.
- L'UV, la pompe décoration, la pompe filtration et la mise à niveau sont commandés via contacteurs TOMZN 25 A a bobine 12 VDC.
- La pompe de filtration dispose d'un départ séparé de l'UV, de la pompe décoration et de la mise à niveau afin de limiter les coupures communes entre organes essentiels et secondaires.
- Le depart cote maison vers le coffret bassin doit etre protege par un disjoncteur dedie 16 A. La liaison d'environ 20 m est confirmee en 3G2,5 mm2, mais le cable est en attente sans disjoncteur au tableau maison : cette protection doit etre achetee et installee avant mise en service.
- Le TeSys VCDN20 trouve en atelier est un candidat de coupure locale cadenassable du coffret FAT, place avant l'interrupteur differentiel local, a valider au schema electrique final.
- Un depart eclairage exterieur supplementaire doit etre reserve dans le coffret ; il reste hors fonctions bassin et il est protege par disjoncteur 6 A courbe C.
- Le débit de rinçage de référence ne doit pas être confondu avec le débit maximal de 60 L/min, car le point de fonctionnement dépendra des buses déjà fabriquées et des pertes de charge.
- Le support du FAT devra fixer la cote altimetrique du trop-plein par rapport au niveau hydraulique du bassin. Cette cote doit être mesurée sur site avant fabrication du support ; elle ne doit pas être inventee en spécification.
- La pompe décoration aspirant au même endroit que la pompe principale, elle doit suivre les mêmes règles de sécurité hydraulique.
- Les diametres d'interconnexion existants 110 mm, 100 mm, 63 mm et 32 mm doivent être preserves dans les choix d'implantation et de pilotage.

## Reperes de niveau à définir

| Repere | Description | État |
| --- | --- | --- |
| Niveau normal côté sale | Niveau nominal observé dans la chambre eau sale en fonctionnement etabli | Hypothèse de travail: environ 20 cm au-dessus du bas du tambour, soit environ 27 cm depuis le fond du filtre |
| Niveau normal côté propre | Niveau nominal observé dans la chambre eau propre et sur le report de niveau | À définir |
| Niveau de declenchement du lavage | Niveau côté eau propre à partir duquel le FAT doit lancer un cycle de lavage | À définir |
| Niveau bas de sécurité | Niveau côté eau propre à partir duquel l'installation passe en état de sécurité | À définir |

### Contraintes sur ces reperes

- Le niveau bas de sécurité doit rester au-dessus du niveau minimal acceptable pour protéger pompes, UV et hydraulique.
- Le niveau de declenchement du lavage et le niveau bas de sécurité sont mesures côté eau propre sur le report de niveau.
- Le niveau de declenchement du lavage doit rester suffisamment sous le trop-plein physique à 30,5 cm pour laisser une marge de reaction.
- Les niveaux normaux côté sale et côté propre serviront de référence pour comprendre le comportement hydraulique du filtre propre.
- Les ecarts eau sale / eau propre peuvent rester utiles pour les observations de mise au point, mais ils ne constituent pas la logique de pilotage V1.
- Ces reperes devront être convertis en cotes physiques mesurables depuis le fond du filtre.
- La surface de filtration utile finale dépendra de la geometrie des ouvertures du tambour sous la toile inox 74 microns. L'objectif V1 est d'obtenir environ 0,20 à 0,23 m2 de surface filtrante utile ; le calcul doit être valide avant découpe ou perçage.

## Politique de sécurité en cas de niveau bas

### Équipements à couper ou inhiber

| Équipement | Action attendue | Justification |
| --- | --- | --- |
| Pompe principale de filtration | Coupure | Éviter de vider le bassin et protéger la pompe contre la marche à sec |
| Pompe décoration | Coupure | Même point d'aspiration que la pompe principale : même protection contre vidange du bassin et marche à sec |
| UV | Coupure | Éviter un fonctionnement hors d'eau sans refroidissement correct |
| Rotation du tambour | Inhibition | Éviter un cycle FAT en situation d'eau insuffisante |
| Pompe de rinçage | Inhibition | Éviter un lavage inutile ou degradant en situation anormale |
| Mise à niveau automatique du bassin | Coupure | Éviter de remplir indefiniment un bassin en cas de fuite |

### Équipements hors sorties contrôlées

| Équipement | Action attendue | Justification |
| --- | --- | --- |
| Bulleur cuve bio | Branchement direct 220 V, hors contrôleur | Préserver les bactéries de filtration biologique |
| Bulleur bassin | Branchement direct 220 V, hors contrôleur | Maintenir l'oxygénation des poissons et limiter la glace en hiver |

## Travaux restants sur le FAT existant

### Mécanique et hydraulique

- Réaliser les ouvertures dans le tuyau qui sert de tambour.
- Poser la maille inox autour du tambour.
- Raccorder la rampe d'aspersion déjà fabriquée à la pompe de rinçage.
- Percer une paroi du filtre pour la prise d'eau de la pompe de rinçage.
- Mesurer le débit réel de rinçage et vérifier la pression ou qualité de jet aux buses.
- Percer le trou de vidange du filtre.
- Installer le joint a levre autour du tambour pour separer eau propre et eau sale.
- Fabriquer le support du FAT afin de positionner correctement le trop-plein par rapport au bassin.

### Instrumentation et automatisme

- Fixer EP_LAVAGE et EP_CRITIQUE sur le tube de report en 32 mm, sur supports réglables en hauteur.
- Valider le sens de rotation, le courant réel et la fixation du motorreducteur Fyearfly 12 VDC 10 rpm.
- Finaliser et tester la transmission 2:1 en engrenages PETG module 4, angle 20 degres, pignon 30 dents sur moyeu aluminium et couronne 60 dents en 3 segments avec queues d'aronde axiales, vissés sur la plaque latérale du tambour.
- Installer l'alimentation Mean Well NDR-120-12 et le porte-fusibles ATO 4 departs.
- Choisir, acheter et cabler le disjoncteur 16 A dedie cote maison pour alimenter le coffret bassin.
- Integrer le TeSys VCDN20 comme sectionneur local cadenassable avant l'interrupteur differentiel du coffret, si son etat est valide.
- Prevoir le depart eclairage exterieur dans le coffret avec disjoncteur 6 A courbe C.
- Concevoir le support imprime 3D du relais HELLA pour montage rail DIN.
- Concevoir l'adaptateur imprime 3D du porte-fusibles ATO pour montage rail DIN si le composant retenu n'est pas DIN natif.
- Concevoir et integrer toute la partie intelligence et pilotage du FAT.
- Ajouter un capot transparent de fermeture avec fin de course OMRCH ME-8104 pour la détection d'ouverture, monte en boucle fail-safe capot fermé = contact fermé.
- Ajouter une sonde de température d'eau maintenable dans une eau représentative : arrivée gravitaire avant pompe/UV ou bassin en zone brassée.
- Ajouter une sonde de température ambiante hors coffret, sur support ventilé et représentatif de l'air du local.
- Integrer l'IHM locale retenue : LCD 2004 / 20x4 I2C 3,3 V, commandes physiques et voyants complémentaires.
- Prévoir une extension Wi-Fi V2 de remontée à distance de l'état et des alarmes sans remplacement de la plateforme principale.
- Prévoir pour une V2 les notifications immédiates actionnables et leur politique anti-repetition : apparition, rappel rare et retour à la normale.
- Prévoir pour une V2 une synthèse quotidienne de fonctionnement et la possibilité de la désactiver.
- La pompe décoration pourra être pilotée en V1.1/V2 par deux plages horaires maximum par jour, identiques tous les jours, avec interrupteur logiciel actif/inactif pour les longues périodes d'arrêt dont l'hiver.
- Définir la liste finale des alarmes indirectes et leur formulation utilisateur.
- Définir pour une V1.1 un test journalier automatique avec diagnostic.
- Définir pour une V1.1 une stratégie d'indexation du tambour pour repartir l'immersion.
- Définir pour une V1.1 les statistiques de lavage pertinentes pour suivre l'état du filtre.
- Définir pour une V1.1 ou V2 un indice simple d'encrassement exploitable dans le temps.
- Définir pour une V1.1 ou V2 une estimation empirique de la consommation d'eau du rinçage et du besoin d'appoint associé.
- Définir pour une V1.1 les temps de fonctionnement cumulés des organes principaux.

## Points techniques restant à valider

Les choix de principe sont maintenant tranchés pour le MVP, sauf les cotes de niveau qui dépendent directement des mesures terrain. Les points ci-dessous sont donc des validations, réglages ou références finales, pas des remises en cause de l'architecture matérielle.

### Question encore ouverte

- Cotes exactes du niveau normal côté sale, du niveau normal côté propre, du seuil de lavage et du niveau bas de sécurité.
- Cotes exactes de réglage EP_LAVAGE et EP_CRITIQUE sur le tube de report après mesure du niveau réel.

### Validations terrain et réglages

- Couple réel, vitesse finale tambour, courant en charge et comportement de protection du moteur de tambour Fyearfly, en reference au couple fournisseur annonce de 70 kg.cm pour la variante 10 tr/min.
- Faux-rond, jeu d'engrenement, usure et tenue mécanique de la transmission PETG module 4, 20 degres, 30/60 dents, largeur 25 mm, avec couronne segmentée vissée et queues d'aronde axiales.
- Débit réel, pression utile aux buses, amorçage et courant réel de la pompe de rinçage.
- Forme, nombre et surface totale des ouvertures du tambour a calculer avant découpe pour atteindre environ 0,20 à 0,23 m2 de surface filtrante utile.
- Référence finale du coffret IP55 minimum, préférence IP65, avec presse-étoupes et gestion de condensation si nécessaire.
- Référence finale du disjoncteur 16 A dedie cote maison et validation de la liaison existante d'environ 20 m jusqu'au coffret bassin.
- Référence finale de l'interrupteur différentiel 2P 30 mA 40 A, type A.
- Cablage final de l'interrupteur-sectionneur cadenassable TeSys VCDN20 avant le differentiel local si reutilise.
- Référence finale materielle du disjoncteur 6 A courbe C pour l'eclairage exterieur, section du cable et separation claire avec les fonctions bassin.
- Validation banc des deux sondes DS18B20 étanches inox identiques : brochage réel, lecture 3,3 V, pull-up 4,7 kΩ, perte de sonde et identification eau/local.
- Validation banc du LCD 2004 / 20x4 I2C 3,3 V : adresse, contraste, retroeclairage, lisibilite et niveaux logiques `SDA` / `SCL`.
- Validation physique de l'ordre EP_LAVAGE au-dessus de EP_CRITIQUE, et des règles d'incohérence associées.
- Mesure empirique de la consommation d'eau de rinçage après mesure du débit réel et des durées de cycle.

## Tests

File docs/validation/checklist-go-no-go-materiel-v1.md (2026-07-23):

# Checklist go/no-go materiel V1

## Objet

Cette checklist sert de verrou avant cablage final, mise en eau reelle puis exploitation autonome du controleur de filtre a tambour.

Un point non valide peut etre accepte uniquement s'il est marque comme non applicable, reporte explicitement hors V1, ou couvert par une action corrective documentee. Les points de securite critiques doivent etre passes avant exploitation sans presence humaine.

## References finales

| Point | Critere go/no-go | Statut | Preuve / commentaire |
| --- | --- | --- | --- |
| Plateforme controle | KC868-A16 ESP32 classique disponible, revision identifiee et inspectee ; ni A16S ni A16v3 | Partiel | Carte recue : KC868-A16 REV.1.6.3, ESP32-WROOM-32. Scan I2C interne passe ; inspection complete borniers, Ethernet et GPIO auxiliaires a terminer (VR-0001). |
| Alimentation 12 VDC | Mean Well NDR-120-12 disponible, entree/sortie reperees | A faire | |
| Capteurs niveau | 2 x CR18-8DN disponibles, brochage confirme | A faire | |
| Pompe rincage | VEVOR / Leo EKJ-802S conservee comme reference V1 | A faire | |
| Moteur tambour | Fyearfly 12 VDC 10 rpm disponible, fixation definie | A faire | |
| Relais tambour | HELLA 4RD 933 332-551 disponible, support rail DIN defini | A faire | |
| Contacteurs auxiliaires | TOMZN TOCT1-25Z 12 VDC valides ou alternative definie | A faire | |
| Relais interface rincage | Bobine 12 VDC < 500 mA, montage DIN, suppression et contact cible AC-15 >= 1 A sous 230 VAC valides | A faire | Reference a choisir avant commande. |
| Contacteur rincage | Schneider TeSys LC1D18P7 avec bobine 230 VAC valide au schema derriere le relais d'interface | A faire | Remplace le LC1D12P7 ; confirmer encombrement, bornes et reperage avant cablage. |
| Capot | OMRCH ME-8104 disponible, came/support definis | A faire | |
| IHM | LCD 2004, boutons, voyants et etiquettes facade definis | Partiel | LCD 2004 valide sur banc a `0x27`, alimente en 3,3 V et lisible avec la RTC; boutons, voyants et etiquettes restent a faire. |
| RTC / temperature | DS3231 et 2 x DS18B20 disponibles, adresses/brochages verifies | Passe sur banc | RTC DS3231 validee a `0x68`; DS18B20 validees sur GPIO14. La cohabitation RTC + LCD est tracee dans VR-0001. |
| Coffret | Reference coffret choisie, IP65 cible ou IP55 justifie | A faire | |
| Borniers / presse-etoupes | References et quantites suffisantes | A faire | |
| Pieces de rechange | Fusibles ATO, au moins un capteur niveau, une sonde, un bouton, un voyant, et si possible un contacteur spare | A faire | |

## Banc electrique basse tension

| Point | Critere go/no-go | Statut | Preuve / commentaire |
| --- | --- | --- | --- |
| Boot securise | Toutes les sorties controlees restent OFF au boot avant autorisation | Passe | REV.1.6.3 : ACK I2C, ecriture brute `0xFF 0xFF` et mesure physique de `100-200 mV` entre chaque Y1-Y16 et 0 V, sans charge, confirmes. |
| Profil firmware A16 | Revision, adresses PCF8574, cartographie, polarites et ROM DS18B20 correspondent exactement a la carte recue | Partiel | Profil `a16-rev1.6.3-inputs-confirmed-candidate` actif : entrees `0x22 = X1-X8`, `0x21 = X9-X16`, polarite active et sorties `Y1-Y16` confirmees a vide. ROM DS18B20 configurees et lues; RTC `0x68` et LCD `0x27` confirmes. Charges et entrees reelles restent a faire. `validated=false`. |
| Bornes X / Y | `X1` a `X16` identifiees comme entrees et `Y1` a `Y16` comme sorties MOSFET ; l'alias firmware reste trace | Passe a vide | Les 16 entrees X sont confirmees par contact sec : X1-X9 fonctionnelles et X10-X16 par valeurs brutes. Boot OFF, activation individuelle et isolement sont valides sur Y1-Y16, sans charge. |
| Armement firmware | Le build arme reste OFF si profil non valide, boot OFF echoue ou banque I2C absente | Logiciel passe, banc a faire | Matrice de verrous couverte par FT-0002. |
| Perte 12 VDC | Contacteurs et sorties controlees retombent OFF par conception | A faire | |
| Distribution 12 VDC | Fusibles 5 A moteur, 3 A automate, 1 A capteurs/boutons, 1 A IHM/accessoires coherents apres mesure | A faire | |
| CR18-8DN repos/detection | `EP_LAVAGE` et `EP_CRITIQUE` lus correctement sur KC868-A16 ; courant d'entree et sens logique documentes | A faire | |
| Rupture fils niveau | Fils marron, bleu et noir de chaque capteur testes et comportement documente | A faire | |
| Incoherence niveau | Incoherence critique declenche defaut bloquant hydraulique | A faire | |
| Contact capot | Capot ferme = boucle fermee ; capot ouvert, fil coupe ou debranche = capot ouvert | A faire | |
| Boutons / selecteur | AUTO et MAINTENANCE exclusifs ; reset, test, manuel tambour et manuel rincage lus sans confusion | A faire | |
| Voyants | Marche, lavage et alarme visibles et conformes a l'affectation V1 | A faire | |
| LCD | Adresse, contraste, lisibilite, reboot et pull-up I2C 3,3 V verifies | Passe sur banc initial | LCD 2004 detecte a `0x27`, alimente en 3,3 V, informations et heure lisibles. Lignes SDA/SCL au repos : 3,287 V; aucun pull-up externe ajoute. Reboot et essai prolonge a integrer au test systeme. |
| RTC | Adresse `0x68`, conservation heure apres coupure, pull-up 3,3 V verifies | Passe sur banc | DS3231 detectee a `0x68`, heure et diagnostics RTC conformes lors du test dedie. |
| I2C partage | LCD + RTC stables ensemble sur `GPIO32` / `GPIO33` pendant essai prolonge | Passe sur banc initial | Scan commun : `0x27` LCD et `0x68` RTC; affichage de l'heure RTC sur LCD confirme. Essai d'endurance reste a faire. |
| DS18B20 | Brochage reel, pull-up 4,7 kOhm, identification eau/local et perte de sonde verifies | Passe | Brochage 3,3 V et pull-up valides sur GPIO14. ROM configurees : `TEMP_BASSIN = 28A3AFC800000062`, `TEMP_LOCAL = 284C19CC000000B2`. Lectures reelles et role verifies par rechauffement doux. Deconnexion des deux sondes : 0 sonde detectee et deux temperatures correctement invalidees, sans valeur fictive. |

## Puissance 230 VAC et coffret

| Point | Critere go/no-go | Statut | Preuve / commentaire |
| --- | --- | --- | --- |
| Revue externe | Schema 230 VAC relu par personne competente avant mise sous tension | A faire | |
| Protection amont | Depart maison 16 A confirme et coherent avec la liaison existante | A faire | |
| Tete tableau | Sectionneur local, differentiel 30 mA type A et disjoncteurs aval conformes au schema | A faire | |
| Separation BT/secteur | Cheminements, borniers, reperes et distances propres dans le coffret | A faire | |
| Terre | Pompe de rincage, coffret/equipements classe I et masses raccordes selon schema | A faire | |
| Contacteur rincage | Sortie MOSFET A16 vers relais d'interface 12 VDC, puis bobine 230 VAC commandee par son contact, avec separation et reperage clairs | A faire | |
| Contacteurs TOMZN | Consommation bobine, echauffement, bruit et coupure 12 VDC observes | A faire | |
| Pompe filtration prioritaire | Depart filtration separe du depart UV / decoration / mise a niveau | A faire | |
| Bulleurs | Bulleurs hors sorties controlees et clairement identifies comme alimentation permanente locale | A faire | |
| Condensation | Entrees cables, boucles goutte, presse-etoupes et traitement passif definis | A faire | |
| Reserve coffret | Place libre rail DIN et borniers suffisante pour maintenance et V1.1/V2 | A faire | |

## Mesures mecaniques et hydrauliques

| Point | Critere go/no-go | Statut | Preuve / commentaire |
| --- | --- | --- | --- |
| Courant moteur tambour | Courant a vide, en charge, au demarrage et blocage controle mesure | A faire | |
| Fusible moteur | Fusible 5 A confirme ou ajuste apres mesure | A faire | |
| Rotation tambour | Sens, vitesse, couple et absence de blocage valides en conditions reelles | A faire | |
| Transmission | Engrenages PETG module 4, angle 20 degres, largeur 25 mm, rapport 30/60 soit 2:1 ; moyeu aluminium sur arbre D 8 mm ; couronne alesage 160 mm en 3 segments avec queues d'aronde axiales, 4 vis M4/segment sur PCD 198 mm ; entraxe reglable autour de 180 mm, faux-rond, jeu, serrage, absence de points durs et usure initiale valides | A faire | |
| Rincage | Jet suffisant observe sur rampe et buses reelles | A faire | |
| Debit rincage | Debit aux buses mesure ; estimation L/cycle documentee | A faire | |
| Seuils niveau | `EP_LAVAGE` et `EP_CRITIQUE` regles apres observation terrain | A faire | |
| Supports capteurs | Supports reglables, accessibles, nettoyables et reperes | A faire | |
| Tube report niveau | Tube 32 mm et event 1 mm inspectables et inclus dans maintenance | A faire | |
| Reserve troisieme capteur | Emplacement et passage cable prevus sans cablage V1 obligatoire | A faire | |

## Essais fonctionnels bloquants

| Point | Critere go/no-go | Statut | Preuve / commentaire |
| --- | --- | --- | --- |
| Lavage nominal | Cycle auto execute, duree mini respectee, retour niveau arrete le cycle | A faire | |
| Duree maximale | Le lavage s'arrete a la duree max configuree | A faire | |
| Tentatives max | Apres 3 tentatives inefficaces, defaut lavage et inhibition auto | A faire | |
| `EP_CRITIQUE` | Coupe ou inhibe filtration, UV, decoration, mise a niveau, tambour et rincage selon schema | A faire | |
| Reprise apres critique | Retour niveau stable puis reset local obligatoire avant reprise | A faire | |
| Capot ouvert | Tambour et rincage interdits ou coupes ; affichage explicite | A faire | |
| Commandes manuelles | Tambour et rincage manuels maintenus seulement si securites OK | A faire | |
| Test lavage | Test borne autorise sous preconditions, refuse avec cause sinon | A faire | |
| Reset refuse | Reset refuse et cause affichee si defaut encore actif | A faire | |
| Reprise secteur | Apres coupure, sorties OFF puis retour selon selecteur et securites | A faire | |
| LCD absent | Fonction automate maintenue, diagnostic degrade signale si possible | A faire | |
| RTC absente | Fonction automate maintenue avec horodatage inconnu | A faire | |
| Sonde temperature absente | Alerte informative sans inhibition lavage/filtration V1 | A faire | |

## Mise en service progressive

| Etape | Critere go/no-go | Statut | Preuve / commentaire |
| --- | --- | --- | --- |
| 1. Simulation table | Entrees/sorties et IHM valides sans puissance dangereuse | A faire | |
| 2. Coffret sans charges | Alimentation, protections, boot et commandes testes charges deconnectees | A faire | |
| 3. Contacteurs | Commandes contacteurs validees sans comportement inattendu | A faire | |
| 4. Manuel terrain | Tambour et rincage testes en manuel sous presence humaine | A faire | |
| 5. Auto surveille | Plusieurs cycles auto observes sans lavage intempestif | A faire | |
| 6. Exploitation normale | Fonctionnement prolonge observe, alarmes et reprise secteur testees | A faire | |

## Exploitation et maintenance

| Point | Critere go/no-go | Statut | Preuve / commentaire |
| --- | --- | --- | --- |
| Angles morts V1 | Defauts non detectes directement documentes | A faire | |
| Fiche plastifiee | Fiche coffret avec voyants, reset, maintenance, coupure generale et alarmes critiques | A faire | |
| Procedure tiers | Une personne autre que le concepteur peut lire l'etat, couper, mettre en maintenance et demander aide | A faire | |
| Inspection periodique | Nettoyage tube niveau, event, buses, toile, capot et condensation planifie | A faire | |
| Documentation mesures | Courant, debit, seuils, essais et revue 230 VAC archives dans le dossier projet | A faire | |

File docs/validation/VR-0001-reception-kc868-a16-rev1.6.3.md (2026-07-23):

# VR-0001 - Reception et identification KC868-A16 REV.1.6.3

## Objet

Tracer l'identification de la carte effectivement recue et les premiers constats non destructifs avant toute alimentation de charge ou armement des sorties.

## Carte recue

| Champ | Constat | Statut |
| --- | --- | --- |
| Reference serigraphiee | `KC868-A16` | Confirme |
| Revision PCB | `REV.1.6.3` | Confirme |
| Famille | A16 classique a ESP32-WROOM-32 et sorties MOSFET | Confirme par serigraphie et inspection visuelle ; ni A16S ni A16v3 |
| Date de reception / constat | 2026-07-22 | Trace |
| Firmware de banc | `kc868_a16_hw_safe` | Utilise |
| Armement des sorties | `HARDWARE_OUTPUTS_ARMED=0`, profil non valide | Confirme par diagnostic |

La photo de reception est conservee dans les pieces jointes de la tache Codex. Elle montre la serigraphie `KC868-A16 REV.1.6.3` et le module ESP32-WROOM-32.

## Nomenclature physique retenue

La serigraphie de la carte est la reference de cablage :

- `X1` a `X16` : entrees digitales physiques ;
- `Y1` a `Y16` : sorties MOSFET physiques ;
- `GND` du bornier d'entrees : retour des essais en contact sec ;
- `12V/24V DC Input` ou `VIN` : alimentation des groupes de sorties, a laisser deconnectee lors des premiers essais d'E/S sans charge.

Dans le firmware et les documents fonctionnels, `I1` a `I9` et `O1` a `O9` restent des **alias logiques**. Ils se raccordent respectivement a `X1` a `X9` et `Y1` a `Y9`. Les voies `X10` a `X16` et `Y10` a `Y16` sont reservees en V1.

## Resultat du premier demarrage securise

Le scan interne et les diagnostics suivants ont ete obtenus avec la carte alimentee, l'USB connecte, aucune charge raccordee et les groupes de sorties non alimentes :

```text
I2C interne : 0x21, 0x22, 0x24, 0x25
Entrees : Raw 0xFF 0xFF ; banques 1 et 2 OK
Sorties : boot OFF OK ; Raw sorties 0xFF 0xFF ; banques 1 et 2 OK
Armement : demande NO ; profil valide NO ; sorties effectivement armees NO
```

Le premier scan a identifie les quatre adresses mais pas leur role. Les essais en contact sec ont ensuite confirme `X1` -> `MANU_RINCAGE` avec le profil generique, puis `X9` -> `EP_LAVAGE`, `X10` -> `EP_CRITIQUE` et `X16` -> `MANU_TAMBOUR`. Ils prouvent l'ordre reel des banques d'entrees : `0x22` porte `X1` a `X8`, puis `0x21` porte `X9` a `X16`.

Apres selection du profil REV.1.6.3, les neuf entrees fonctionnelles sont confirmees dans l'ordre attendu : `X1` `EP_LAVAGE`, `X2` `EP_CRITIQUE`, `X3` `CAPOT_OUVERT`, `X4` `MODE_AUTO`, `X5` `MODE_MAINTENANCE`, `X6` `RESET_ALARME`, `X7` `TEST_LAVAGE`, `X8` `MANU_TAMBOUR`, `X9` `MANU_RINCAGE`. Les voies reservees sont aussi confirmees par le diagnostic brut : `X10` `0xFF 0xFD`, `X11` `0xFF 0xFB`, `X12` `0xFF 0xF7`, `X13` `0xFF 0xEF`, `X14` `0xFF 0xDF`, `X15` `0xFF 0xBF`, `X16` `0xFF 0x7F`.

Le firmware selectionne donc le profil non valide `a16-rev1.6.3-inputs-confirmed-candidate` : `GPIO4/GPIO5`, entrees `0x22` / `0x21`, sorties `0x24` / `0x25`. Les quatre adresses repondent et aucune erreur I2C n'est memorisee. L'ecriture OFF a ete acceptee avant toute commande de sortie.

Les deux banques de sorties ont ensuite ete alimentees en 12 V, sans charge. Au demarrage du build safe, la tension mesuree entre chaque borne `Y1` a `Y16` et le 0 V d'alimentation est comprise entre **100 mV et 200 mV**. Cette mesure confirme physiquement l'etat OFF au boot sur les 16 sorties. Elle ne valide pas encore la commande ON, la polarite active ni l'affectation individuelle des sorties.

Le 2026-07-22, le build dedie `kc868_a16_hw_output_test` a ensuite ete utilise, toujours sans charge. Les commandes `diag output 1 pulse 1000` a `diag output 16 pulse 1000` ont produit **12 V pendant 5 s** sur la seule borne cible `Y1` a `Y16` (la limite du build de banc est 5 000 ms). Les voyants des quinze autres voies sont restes eteints lors de chaque essai. Cette preuve confirme la polarite active et l'isolement entre voies sur les 16 sorties, ainsi que la correspondance `O1-Y1` a `O9-Y9` ; `Y10-Y16` sont confirmees comme voies reservees dans l'ordre physique.

## Validation auxiliaire RTC + LCD

Le 2026-07-23, la RTC DS3231 a ete testee seule sur le bus I2C auxiliaire `Wire1`, configure sur `HT1` / `GPIO32` pour `SDA` et `HT2` / `GPIO33` pour `SCL`. Elle repond a l'adresse `0x68`; sa lecture d'heure, son etat et les essais de banc ont ete declares conformes.

Le LCD 2004 I2C a ensuite ete alimente en `3,3 V` et raccorde en parallele sur les memes lignes `SDA`/`SCL`. Le niveau de repos mesure sur chacune des deux lignes est **3,287 V**. Aucun pull-up externe n'a ete ajoute. Le scan du programme de banc `kc868_a16_rtc_lcd_test` retourne :

```text
--- SCAN I2C HT1/HT2 ---
Trouve : 0x27
Trouve : 0x68
Nombre de peripheriques : 2
```

Le LCD est donc confirme a l'adresse `0x27`, la RTC a `0x68`, et leur cohabitation immediate sur le meme bus est validee : les informations de test et l'heure RTC sont lisibles sur l'ecran. Le programme de banc maintient explicitement les sorties `Y` a l'etat OFF.

## Prochaines preuves requises

1. Tester chaque voyant et chaque bobine apres mesure de courant et verification des suppressions de surtension.
2. Valider les entrees avec les organes reels : CR18-8DN, contact capot, selecteur et boutons.
3. Completer les essais d'endurance du bus I2C partage et l'integration de l'affichage IHM complet.

Pour les DS18B20 retenues, le brochage confirme par leur documentation est rouge = `VCC`, noir = `GND`, jaune = `DATA`. Le fil jaune doit aller au bornier utilisateur `HT3` / `GPIO3` de la carte, qui correspond a `GPIO14` dans le firmware, avec une resistance de pull-up `4,7 kΩ` entre ce signal et `3.3 V`. La borne `X14` est une entree digitale optocouplee et ne doit pas etre utilisee.

Le 2026-07-23, les deux DS18B20 ont ete detectees sur le bus 1-Wire `GPIO14` : `284C19CC000000B2` et `28A3AFC800000062`. Leur alimentation 3,3 V, masse commune, signal et pull-up sont donc fonctionnels. Leur association physique confirmee est `TEMP_BASSIN = 28A3AFC800000062` et `TEMP_LOCAL = 284C19CC000000B2`; ces ROM sont inscrites dans le profil REV.1.6.3, sans jamais dependre de l'ordre de decouverte. Apres reflash du build safe, `diag temp` a affiche les deux valeurs valides et le rechauffement doux de chaque sonde a fait varier uniquement la ligne de son role attendu : lecture et affectation sont validees.

L'essai de deconnexion des deux sondes est valide : `diag temp` affiche `Sondes detectees: 0`, conserve les ROM configurees et retourne `TEMP_BASSIN: INVALIDE` ainsi que `TEMP_LOCAL: INVALIDE`. Aucune valeur fictive n'est injectee apres perte du bus.

Le profil ne pourra passer a `validated=true` qu'apres les preuves restantes ci-dessus et mise a jour de la checklist go/no-go.

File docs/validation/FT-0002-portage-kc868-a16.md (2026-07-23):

# FT-0002 - Portage firmware KC868-A16

## Objet

Tracer la preuve logicielle du portage de la couche materielle KC868-A32 vers la KC868-A16 ESP32 classique et definir le verrou restant avant tout armement physique.

## Statut

**Logiciel passe ; validation sur carte en cours.** La carte recue est une **KC868-A16 REV.1.6.3**. Aucun profil materiel n'est encore marque `validated` et le build `kc868_a16_hw_armed` reste effectivement desarme.

## Preuve automatisee

Commandes de reference :

```powershell
cd firmware
python -m platformio test -e native
python -m platformio run -e kc868_a16_sim -e kc868_a16_hw_safe -e kc868_a16_hw_armed
# Banc de sorties local seulement : jamais utilise par la CI ni en exploitation.
python -m platformio run -e kc868_a16_hw_output_test
```

Resultat local du 2026-07-22 :

- 56 tests host-side passes ;
- compilation reussie des trois environnements A16 ;
- aucune image n'est televersee ou publiee par la CI.

La couverture A16 verifie notamment :

- deux banques de huit entrees et deux banques de huit sorties ;
- passage I8/I9 et O8/O9 ;
- polarites d'entree et de sortie configurables ;
- ecriture des deux banques de sorties a OFF avant l'initialisation des entrees ;
- profils candidats standard, REV1.5 et REV1.6.3 tous non valides ;
- ordre physique complet des entrees REV.1.6.3 : `X1-X9` fonctionnelles et `X10-X16` verifiees par valeurs brutes ;
- banque d'entree absente ;
- echec d'ecriture de sortie verrouille jusqu'au redemarrage ;
- refus de toute sortie si un verrou manque : build arme, profil valide, boot OFF, entrees saines ou sorties saines.

## Environnement d'impulsions de test des sorties

`kc868_a16_hw_output_test` est un environnement de banc distinct. Il conserve `HARDWARE_OUTPUTS_ARMED=0` et force donc les demandes du controleur a OFF a chaque boucle. Il ne permet qu'une commande serie `diag output <1-16> pulse <ms>`, bornee a 5 000 ms dans ce build de banc (1 000 ms dans les autres builds) et refusee si le boot OFF, les deux banques d'entrees, les deux banques de sorties ou le verrou de defaut ne sont pas sains.

Le profil REV.1.6.3 reste `validated=false` : son indicateur separe d'impulsions de diagnostic est ouvert uniquement parce que les entrees physiques et le boot OFF des 16 sorties ont ete prouvés. Cet environnement n'est ni un build d'exploitation, ni une autorisation de raccorder une charge.

## Reception REV.1.6.3 et premier demarrage securise

Le 2026-07-22, le build `kc868_a16_hw_safe` a ete execute avec une KC868-A16 REV.1.6.3 alimentee et sans charge. Le scan interne a detecte `0x21`, `0x22`, `0x24` et `0x25` sur `GPIO4/GPIO5`; les deux banques d'entrees et les deux banques de sorties sont saines. Les ecritures boot OFF ont retourne `0xFF 0xFF` et aucune sortie ne peut etre armee dans cet environnement. Les groupes de sorties ont ensuite ete alimentes en 12 V : chaque borne Y1-Y16 mesure 100 a 200 mV au boot, ce qui valide l'etat OFF physique sans charge.

La serigraphie de la carte utilise `X1` a `X16` pour les entrees et `Y1` a `Y16` pour les sorties MOSFET. Les termes `I1` a `I9` et `O1` a `O9` du firmware restent des alias fonctionnels : `I1` = `X1` et `O1` = `Y1`, dans l'ordre jusqu'a 9. Les essais par contact sec ont confirme que `0x22` porte `X1` a `X8` et `0x21` porte `X9` a `X16` : un profil REV.1.6.3 dedie inverse donc l'ordre des deux banques d'entrees par rapport au candidat generique. Les neuf fonctions X1-X9 et les valeurs brutes de X10-X16 sont confirmees. Le banc sans charge confirme aussi le boot OFF, la polarite active et l'activation isolee de `Y1-Y16`.

La fiche de reception detaillee est [VR-0001](VR-0001-reception-kc868-a16-rev1.6.3.md).

## Profils candidats non valides

| Profil | Entrees | Sorties | Usage |
| --- | --- | --- | --- |
| `a16-classic-standard-candidate` | `0x21`, `0x22` | `0x24`, `0x25` | Profil de scan initial par defaut. |
| `a16-rev1.5-green-candidate` | `0x39`, `0x3A` | `0x3C`, `0x3D` | Candidat seulement si la revision et l'etiquette correspondent. |
| `a16-rev1.6.3-inputs-confirmed-candidate` | `0x22` (`X1-X8`), `0x21` (`X9-X16`) | `0x24`, `0x25` | Profil selectionne pour les builds materiels ; E/S confirmees a vide, reste non valide tant que les charges et auxiliaires ne sont pas verifies. |

Le scan ne deduit jamais le role des adresses. Une adresse differente, par exemple `0x3B` observee sur certaines cartes, impose la creation d'un profil correspondant a la carte recue.

## Procedure bloquante a reception

1. Confirmer KC868-A16 ESP32-WROOM-32 classique, revision PCB et absence de confusion avec A16S/A16v3.
2. Flasher `kc868_a16_hw_safe`, sans charge et avec les alimentations de banques de sorties deconnectees.
3. Executer `diag i2c`, relever les quatre PCF8574 et fixer explicitement leurs roles ; pour la REV.1.6.3 recue, `0x22 = X1-X8` et `0x21 = X9-X16` sont confirmes.
4. Etat OFF au boot physiquement confirme sur Y1 a Y16, sans charge. Flasher `kc868_a16_hw_output_test`, puis tester l'etat ON et la polarite avec les impulsions diagnostiques controlees.
5. Les contacts secs X1 a X16 sont confirmes. Tester ensuite les CR18-8DN au repos, en detection et avec chaque fil debranche.
6. Le profil nomme de la carte recue contient l'ordre des banques d'entrees, la polarite des sorties et les ROM des deux DS18B20 confirmes. Valider ensuite LCD, RTC, charges et essai de deconnexion des sondes.
7. Passer ce profil a `validated=true` uniquement apres archivage des mesures precedentes.
8. Tester `diag output <1-16> pulse <ms>` sans charge, puis avec voyants et bobines une par une apres mesure du courant et validation des suppressions de surtension.

## Auxiliaires

Le bus interne PCF8574 reste sur GPIO4/GPIO5. Un second bus I2C utilise GPIO32/GPIO33 pour le LCD 2004 et la RTC DS3231 ; le bus 1-Wire utilise GPIO14.

Commandes de diagnostic :

- `diag aux i2c` : scan LCD/RTC ;
- `diag rtc` : presence, perte d'alimentation et validite de l'heure ;
- `diag temp` : ROM des sondes detectees et affectations eau/local.

L'absence du LCD ou de la RTC ne bloque pas l'automate. Une sonde DS18B20 non configuree ou absente reste invalide et declenche le comportement A11/A12 existant, sans valeur fictive de remplacement.

## Critere de cloture

FT-0002 ne pourra etre declaree completement passee qu'apres validation physique du boot OFF et des 16 sorties, des auxiliaires et mise a jour de la checklist go/no-go materiel.

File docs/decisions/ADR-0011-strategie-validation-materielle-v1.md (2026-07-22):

# ADR-0011 - Strategie de validation materielle V1

## Statut

Acceptee

## Contexte

L'architecture materielle V1 du controleur de filtre a tambour est maintenant largement fixee : plateforme KC868-A16 ESP32 classique selon ADR-0012, alimentation 12 VDC, capteurs de niveau CR18-8DN, motorisation tambour 12 VDC, pompe de rincage 230 VAC deja achetee, relais d'interface de rinçage a choisir, contacteurs de puissance, IHM locale, RTC et sondes de temperature.

Ces choix ne sont pas des choix de maquette jetable : ils constituent la base cible du MVP et doivent rester compatibles avec la V2. Cependant, plusieurs points critiques restent conditionnes a des validations banc, schema ou terrain : sens logique des entrees, rupture de fils, etats au boot, perte du 12 VDC, separation basse tension / secteur, comportement des contacteurs, courant moteur, debit de rincage, condensation, reglage des seuils hydrauliques et reprise apres defaut.

La validation materielle doit donc empecher deux erreurs opposees :

- rouvrir inutilement l'architecture a chaque doute mineur ;
- transformer des hypotheses non mesurees en cablage definitif.

## Decision

La V1 retient une validation progressive et bloquante avant exploitation autonome.

Les choix materiels acceptes restent figes par defaut, mais une mesure ou un essai reel peut rouvrir une ADR si le resultat montre une incompatibilite electrique, une limite de securite, un echauffement anormal, un declenchement intempestif, un comportement instable ou une inefficacite hydraulique majeure.

Le banc de test materiel est obligatoire avant cablage definitif du coffret. La carte recue est une `KC868-A16 REV.1.6.3` ; le scan initial et le demarrage desarme sont traces dans [VR-0001](../validation/VR-0001-reception-kc868-a16-rev1.6.3.md). Il doit couvrir au minimum :

- KC868-A16 REV.1.6.3, avec identification de revision, scan I2C, entrees physiques `X1` a `X16` et sorties MOSFET physiques `Y1` a `Y16` desarmees ;
- capteurs CR18-8DN `EP_LAVAGE` et `EP_CRITIQUE` ;
- simulation du contact capot ;
- boutons et selecteur AUTO / MAINTENANCE ;
- commandes de relais et contacteurs sans charge dangereuse ;
- LCD 2004 I2C ;
- RTC DS3231 ;
- sondes DS18B20.

Les essais suivants sont bloquants avant mise en eau reelle :

- toutes les sorties controlees sont OFF au boot avant lecture des securites ;
- perte du 12 VDC de commande = contacteurs et sorties controlees OFF par conception ;
- `EP_CRITIQUE` confirme coupe ou inhibe filtration, UV, decoration, mise a niveau, tambour et rincage selon l'architecture retenue ;
- capot ouvert coupe ou interdit tambour et rincage ;
- incoherence critique des capteurs niveau met le systeme en securite ;
- retour apres `EP_CRITIQUE` demande retour niveau stable puis acquittement local ;
- duree maximale de lavage respectee ;
- reset refuse si la cause active persiste ;
- IHM locale affiche la cause principale de refus ou de defaut ;
- rupture ou deconnexion du contact capot est interpretee comme capot ouvert.

La mise en service terrain est progressive :

1. simulation sur table ;
2. coffret alimente sans charges de puissance ou charges deconnectees ;
3. commande des contacteurs ;
4. essai tambour et rincage en manuel ;
5. essai automatique sous presence humaine ;
6. exploitation normale seulement apres plusieurs cycles observes.

Le schema 230 VAC final doit etre relu par une personne competente avant mise sous tension reelle, notamment pour le differentiel, les disjoncteurs, la terre, les sections, les borniers, la separation basse tension / secteur et les cheminements.

La V1 documente explicitement ses angles morts. En particulier, sans capteur dedie, elle ne pretend pas detecter directement un contacteur colle, un relais colle, une pompe de rincage faible mais non arretee, un tambour qui tourne mal, un capteur niveau mal positionne ou un blocage tambour par mesure de courant. Ces cas sont couverts par protections materielles, temporisations, alarmes indirectes, inspection et validation terrain.

Une checklist go/no-go materielle est creee dans `docs/validation/` et doit etre passee avant cablage final puis avant exploitation autonome.

## Consequences

- Les ADR materiels restent utiles et stables, mais le reel garde un droit de veto.
- Les validations banc et terrain deviennent des prerequis, pas de simples recommandations.
- Le dossier doit conserver les mesures de courant moteur, debit de rincage, comportement des capteurs, tests de boot, tests de perte alimentation et revue 230 VAC.
- La pompe de rincage deja achetee reste la reference materielle V1 ; si son essai est insuffisant, les adaptations portent d'abord sur durees, buses, rampe, pression ou conditions de fonctionnement.
- Le troisieme capteur niveau n'est pas ajoute en V1, mais une reserve mecanique et de cablage doit etre prevue.
- Les pieces critiques et references de rechange doivent rester documentees pour faciliter le depannage.
- Une fiche papier plastifiee dans le coffret est retenue comme support d'exploitation local simple.

## Alternatives considerees

- Cablage direct sans banc complet : non retenu, car trop de choix restent conditionnes par des comportements electriques reels.
- Remettre tous les choix materiels en concurrence avant prototype : non retenu, car l'architecture est deja suffisamment convergente et plusieurs composants sont achetes.
- Validation uniquement logicielle : non retenue, car les risques principaux incluent puissance, humidite, hydraulique, capteurs et contacteurs.
- Exploitation autonome apres un seul cycle reussi : non retenue, car les reglages de niveau, la mecanique et le rincage demandent observation terrain.

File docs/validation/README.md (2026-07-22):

# Validation

Ce dossier contient le plan de tests et les preuves de validation du contrôleur de filtre à tambour.

Le principe retenu est une validation tracée exigence par exigence : chaque exigence fonctionnelle ou de sécurité doit être couverte par un test, une inspection ou une justification explicite de report.

Fichier principal :

- [Plan de tests par exigences](plan-tests-exigences.md)
- [Checklist go/no-go materiel V1](checklist-go-no-go-materiel-v1.md)
- [FT-0001 - Scenarios simulateur firmware V0.1](FT-0001-scenarios-simulateur-firmware-v0.1.md)
- [FT-0002 - Portage firmware KC868-A16](FT-0002-portage-kc868-a16.md)
- [VR-0001 - Reception et identification KC868-A16 REV.1.6.3](VR-0001-reception-kc868-a16-rev1.6.3.md)

## Tests automatises host-side

Les scenarios FT-0001 automatisables sont couverts par un banc de tests PlatformIO `native`, sans carte ESP32 et sans moniteur serie :

```powershell
cd firmware
python -m platformio test -e native
```

Le banc pilote directement `Controller::update()` avec des `InputsSnapshot` et un `nowMs` simule. Il se trouve dans `firmware/test/test_ft0001_controller/`.

## Preuve automatisee courante

La preuve automatisee de reference est le workflow GitHub Actions `Firmware`, defini dans `.github/workflows/firmware.yml`.

Ce workflow est execute a chaque push ou pull request touchant le firmware. Il lance :

```powershell
cd firmware
python -m platformio test -e native
python -m platformio run
```

La CI couvre donc :

- les tests host-side FT-0001 du `Controller` ;
- les tests host-side du parsing des commandes simulateur ;
- les tests host-side du buffer de ligne serie ;
- la compilation du firmware ESP32 dans `kc868_a16_sim`, `kc868_a16_hw_safe` et `kc868_a16_hw_armed` ;
- le verrouillage du build `hw_armed` tant que le profil de la carte recue reste non valide.

La preuve locale du portage A16 couvre 51 tests host-side. Limite : cette preuve valide le code, les profils candidats et la compilation, mais ne remplace pas les essais materiels sur carte KC868-A16, les mesures hydrauliques ou la validation des entrees/sorties physiques.

Les procédures longues ou risquées peuvent être détaillées dans des fiches de test séparées, tout en restant référencées par la matrice de traçabilité.

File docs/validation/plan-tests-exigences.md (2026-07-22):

# Plan de tests par exigences

## Objectif

Valider la V1 du contrôleur de filtre à tambour en reliant chaque exigence a une preuve de validation.

Ce plan remplace une simple liste de scénarios critiques. Les scénarios restent utiles, mais ils doivent être rattachés aux exigences qu'ils couvrent.

La structure retenue est double :

- une matrice unique de traçabilité pour prouver que chaque exigence est couverte ;
- des fiches de test séparées pour les procédures complexes, les essais de sécurité, les mesures ou les campagnes sur installation réelle.

## Règles de couverture

- Chaque exigence `Must` doit être couverte avant installation réelle.
- Chaque exigence `Should` doit être couverte, reportée explicitement ou marquée hors itération.
- Chaque exigence `Could` doit être reportée ou couverte si elle est implémentée.
- Un test peut couvrir plusieurs exigences.
- Une exigence peut nécessiter plusieurs tests si elle combine comportement nominal, sécurité et reprise après défaut.
- Les comportements de sécurité doivent être validés par test physique ou sur banc.
- Les exigences documentaires, mécaniques non automatisées ou d'architecture peuvent être validées par inspection, revue ou preuve documentaire.

## Modes de validation

| Mode | Usage attendu |
| --- | --- |
| Test sur banc | Comportement firmware, entrées/sorties, temporisations, interverrouillages et IHM. |
| Test installation | Hydraulique réelle, niveaux, bypass, rinçage, reprise et comportement avec les équipements définitifs. |
| Mesure | Débit, courant, vitesse, température ou toute valeur dimensionnante. |
| Inspection | Câblage, séparation basse tension/puissance, capot, implantation capteurs, protections et conformité documentaire. |
| Revue documentaire | Exigences de formulation, décisions d'architecture, exclusions V1/V2 et traçabilité. |

## Statuts de validation

| Statut | Signification |
| --- | --- |
| À définir | Le test ou la preuve reste à rédiger. |
| Prêt | Le test est décrit et peut être exécute. |
| Passé | Le test a été exécuté avec succès. |
| Échoué | Le test a été exécuté avec un résultat non conforme. |
| Reporté | L'exigence est explicitement reportée hors itération. |
| Non applicable | L'exigence ne s'applique pas à l'itération ou à l'architecture retenue. |
| Passé (host-side) | Le comportement est couvert par test automatisé natif, sans validation matériel. |

## Fiches de test détaillées

Les fiches détaillées doivent être créées lorsque la procédure ne tient pas clairement dans la matrice.

Convention de nommage proposée :

`FT-xxxx-titre-court.md`

Chaque fiche doit contenir au minimum :

- objectif ;
- exigences couvertes ;
- préconditions ;
- matériel nécessaire ;
- procédure ;
- résultats attendus ;
- résultat observé ;
- verdict ;
- date et version testée.

## Matrice de traçabilité

| Exigence | Priorité | Mode de validation | Cas de test / preuve | Critère d'acceptation | Statut |
| --- | --- | --- | --- | --- | --- |
| F-001 | Must | Test | À définir | À définir | À définir |
| F-002 | Must | Test | À définir | À définir | À définir |
| F-003 | Must | Test | À définir | À définir | À définir |
| F-004 | Must | Test | Durée lavage maxi | Un lavage ne dépasse pas la durée maximale configurée, cible initiale 45 s. | Passé (host-side) |
| F-005 | Must | Test | Anti-redémarrage lavage | Deux cycles automatiques ne peuvent pas s'enchaîner sans respecter le délai configuré, cible initiale 30 à 120 s. | Passé (host-side) |
| F-040 | Must | Test | Durée lavage mini | Le rinçage et la rotation restent actifs au moins 10 s au réglage initial, même si EP_LAVAGE revient vite normal. | Passé (host-side) |
| F-031 | Must | Test | Alertes température eau | La sonde DS18B20 `TEMP_BASSIN` est lue en 3,3 V avec pull-up 4,7 kΩ ; les alertes basse < 4 deg C, haute > 28 deg C et perte de mesure A11 sont signalées sans bloquer les fonctions. | À définir |
| F-033 | Must | Test | Alertes température local | La sonde DS18B20 `TEMP_LOCAL` est lue en 3,3 V avec pull-up 4,7 kΩ ; les alertes basse < 2 deg C, haute > 40 deg C et perte de mesure A12 sont signalées sans bloquer les fonctions. | À définir |
| F-041 | Must | Test | Rotation résiduelle | Après arrêt rinçage, le tambour continue pendant la durée résiduelle configurée, cible initiale 2 à 5 s, puis l'anti-redémarrage démarré. | Passé (host-side) |
| F-043 | Must | Test | Relance après échec lavage | Après durée maxi atteinte avec EP_LAVAGE actif, la tentative suivante attend la pause configurée 30 à 120 s. | Passé (host-side) |
| F-044 | Must | Test | Défaut après tentatives max | Après 3 tentatives au réglage initial sans retour normal, le défaut lavage maintenu est déclaré et les lavages auto sont inhibés. | Passé (host-side) |
| F-006 | Must | Test | À définir | À définir | À définir |
| F-066 | Must | Revue documentaire | Formulation indirecte alarmes | Aucun message V1 n'affirme une panne d'organe non instrumentée ; les libellés portent sur effets observés. | À définir |
| F-075 | Must | Test | Alarmes bloquantes V1 | Retour automatique impossible tant que la cause n'a pas disparu et que l'alarme n'est pas acquittée. | À définir |
| F-076 | Must | Test | Reset refusé cause active | Le reset est refusé et l'IHM indique la cause encore active. | Passé (host-side) |
| F-080 | Must | Test | Filtrage EP_LAVAGE | Une activation plus courte que la temporisation configurée ne lance pas de lavage ; une activation maintenue lance le lavage. | À définir |
| F-081 | Must | Test | Confirmation EP_CRITIQUE | Une impulsion plus courte que l'anti-rebond configuré ne déclenche pas la sécurité ; une activation maintenue déclenche la mise en sécurité. | À définir |
| F-082 | Must | Test | Reprise après EP_CRITIQUE | Le système refuse le redémarrage avant retour niveau normal stable et acquittement local valide. | À définir |
| F-083 | Must | Test | Reprise UV après EP_CRITIQUE | Après acquittement, la filtration redémarre avant l'UV et l'UV attend la temporisation de stabilisation. | À définir |
| F-084 | Must | Test | Incohérence capteurs niveau | EP_CRITIQUE actif avec EP_LAVAGE inactif déclenche un défaut bloquant hydraulique et coupe les sorties protégées. | Passé (host-side) |
| F-085 | Must | Test | Reset refusé EP_LAVAGE persistant | Le reset est refusé tant que EP_LAVAGE reste actif après défaut lavage maintenu. | Passé (host-side) |
| F-086 | Must | Test | Capteur niveau non fiable | Le système bloque hydrauliquement si EP_CRITIQUE est non fiable et inhibe seulement les lavages auto si le doute porte uniquement sur EP_LAVAGE. | À définir |
| F-087 | Must | Test | EP_LAVAGE pendant anti-redémarrage | Si EP_LAVAGE revient pendant l'anti-redémarrage, aucun lavage ne repart avant la fin de la temporisation puis confirmation EP_LAVAGE. | À définir |
| F-088 | Must | Test | Priorité affichage alarmes | Si plusieurs alarmes sont actives, l'IHM affiche la plus prioritaire selon l'ordre V1 défini ; une alarme plus prioritaire masque A15 à l'écran sans l'effacer tant que le capot reste ouvert trop longtemps. | À définir |
| F-089 | Must | Test | Message reset refusé | Chaque reset refusé affiche une cause courte et explicite. | À définir |
| F-090 | Must | Test | Bypass supposé | En dégradé sans instrumentation bypass, l'IHM affiche bypass supposé et ne prétend pas mesurer bypass actif. | À définir |
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

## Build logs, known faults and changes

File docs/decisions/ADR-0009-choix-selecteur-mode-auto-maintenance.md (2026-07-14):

# ADR-0009 - Choix du sélecteur de mode AUTO / MAINTENANCE

## Statut

Acceptée

## Contexte

La V1 doit disposer d'une commande locale simple pour choisir l'intention d'exploitation : mode automatique nominal ou mode maintenance. Ce choix doit être lisible en façade, stable mécaniquement et compatible avec les entrées digitales du KC868-A16.

Le capot ouvert reste prioritaire sur le sélecteur : même si le sélecteur est sur AUTO, un capot ouvert force l'état maintenance ou sécurité selon la situation. Le sélecteur n'est donc pas une sécurité de capot ni une coupure de puissance.

Le coffret est installé dans un local technique humide avec condensation et projections possibles. Les organes de façade doivent rester cohérents avec un coffret IP55 minimum, préférence IP65.

## Décision

Le sélecteur physique `AUTO / MAINTENANCE` retenu pour le montage MVP est un sélecteur de façade type XB2-BD25 ou équivalent, avec les caractéristiques suivantes :

- diamètre de perçage 22 mm ;
- 2 positions maintenues, non momentanées ;
- contact `1NO + 1NC` ;
- raccordement en contacts secs basse tension vers les entrées digitales du KC868-A16 ;
- commun raccordé au `GND` des entrées, avec une voie pour `MODE_AUTO` et une voie pour `MODE_MAINTENANCE`.

La validation banc doit confirmer au multimètre le sens réel des contacts et le sens logique lu par le KC868-A16. La position AUTO doit activer `MODE_AUTO`, la position MAINTENANCE doit activer `MODE_MAINTENANCE`, et les deux états doivent rester mutuellement exclusifs.

## Conséquences

- La façade du coffret doit prévoir un perçage 22 mm pour le sélecteur.
- Deux entrées digitales sont réservées pour lire explicitement `MODE_AUTO` et `MODE_MAINTENANCE`.
- Le firmware peut détecter une incohérence si les deux entrées sont actives ou inactives alors que le câblage final devrait imposer un état unique.
- Le sélecteur ne coupe pas directement les organes de puissance ; les sorties restent commandées par la logique automate et les sécurités.
- La référence finale doit confirmer la présence d'un joint de façade, une tenue mécanique correcte, des bornes accessibles et une profondeur compatible avec la porte du coffret.

## Alternatives considérées

- Sélecteur 1NO seul : plus simple, mais moins explicite pour distinguer un vrai mode maintenance d'une rupture de fil ou d'un état non lu.
- Sélecteur 3 positions : non retenu en V1, car les commandes manuel et test sont portées par des boutons dédiés.
- Boutons séparés AUTO et MAINTENANCE : moins lisibles en façade et inutilement plus complexes pour un choix de mode stable.
- Sélecteur avec coupure de puissance : non retenu, car la coupure locale et la consignation sont traitées par l'architecture électrique du coffret, pas par l'entrée de mode automate.

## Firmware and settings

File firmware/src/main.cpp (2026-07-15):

#include <Arduino.h>

#include "app/Config.h"
#include "app/Controller.h"
#include "app/Types.h"
#include "hal/DisplayService.h"
#include "hal/InputService.h"
#include "hal/OutputService.h"
#include "hal/PreferencesPersistentStore.h"
#if USE_KC868_IO
#include "hal/Kc868A16Profile.h"
#include "hal/Kc868Pcf8574Io.h"
#include "hal/Kc868WireI2cBus.h"
#endif
#if USE_A16_AUXILIARIES
#include <LCDi2c.h>
#include <Wire.h>

#include "hal/A16AuxiliaryService.h"
#include "hal/TemperatureService.h"
#endif
#if USE_SIM_INPUTS
#include "sim/SerialSimulator.h"
#elif USE_KC868_IO
#include "hal/Kc868Diagnostics.h"
#endif

namespace {
Config config;
PreferencesPersistentStore persistentStore;
Controller controller(config, &persistentStore);
InputsSnapshot inputs;
OutputsCommand outputs;
DisplayService display;
#if USE_KC868_IO
Kc868WireI2cBus kc868Bus;
Kc868Pcf8574Io kc868Io(kc868Bus, selectedKc868A16Profile());
#if USE_A16_AUXILIARIES
A16AuxiliaryService auxiliaryService(Wire1, selectedKc868A16Profile());
TemperatureService temperatureService(selectedKc868A16Profile());
LCDi2c lcd(selectedKc868A16Profile().auxiliaries.lcdAddress, Wire1);
InputService inputService(&kc868Io, &temperatureService);
#else
InputService inputService(&kc868Io);
#endif
OutputService outputService(&kc868Io);
#else
InputService inputService;
OutputService outputService;
#endif
#if USE_SIM_INPUTS
SerialSimulator simulator;
#elif USE_KC868_IO
Kc868Diagnostics diagnostics;
#endif
}  // namespace

void setup() {
  Serial.begin(115200);
  while (!Serial) {
    delay(10);
  }

  outputService.begin();
#if USE_A16_AUXILIARIES
  auxiliaryService.begin();
#endif
  inputService.begin();
  controller.begin(millis());
#if USE_A16_AUXILIARIES
  display.begin(Serial, auxiliaryService.lcdPresent() ? &lcd : nullptr);
#else
  display.begin(Serial);
#endif
#if USE_SIM_INPUTS
  simulator.begin(Serial);
#elif USE_KC868_IO
#if USE_A16_AUXILIARIES
  diagnostics.begin(Serial, &auxiliaryService);
#else
  diagnostics.begin(Serial);
#endif
#endif
  Serial.println("FAT Controller V0.2");
  display.render(controller.status(), inputs, outputs);
}

void loop() {
  const unsigned long nowMs = millis();

#if USE_A16_AUXILIARIES
  auxiliaryService.poll(nowMs);
#endif

#if USE_SIM_INPUTS
  simulator.poll(inputService.simulatedInputs(), controller, outputs);
#endif
  inputs = inputService.read(nowMs);
#if USE_KC868_IO
  outputService.setInputHardwareHealthy(inputService.hardwareIoHealthy());
#endif
  outputs = controller.update(inputs, nowMs);
  outputService.apply(outputs);

#if USE_SIM_INPUTS
  if (inputService.simulatedInputs().btnReset) {
    inputService.simulatedInputs().btnReset = false;
  }
  if (inputService.simulatedInputs().btnTestLavage) {
    inputService.simulatedInputs().btnTestLavage = false;
  }
#elif USE_KC868_IO
  diagnostics.poll(inputService, outputService, inputs, controller);
#endif

  display.render(controller.status(), inputs, outputService.lastApplied());
}

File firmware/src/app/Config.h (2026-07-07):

#pragma once

#include <stdint.h>

struct Config {
  unsigned long epLavageDelayMs = 10000;
  unsigned long epCritiqueDebounceMs = 1000;

  unsigned long capotOpenDebounceMs = 300;
  unsigned long capotCloseStableMs = 1500;
  unsigned long capotLongOpenMs = 10UL * 60UL * 1000UL;

  unsigned long washMinMs = 10000;
  unsigned long washMaxMs = 45000;
  unsigned long residualRotationMs = 3000;
  unsigned long antiRestartMs = 60000;
  unsigned long retryPauseMs = 60000;

  uint8_t maxWashAttempts = 3;

  float tempBassinLowC = 4.0F;
  float tempBassinHighC = 28.0F;
  float tempLocalLowC = 2.0F;
  float tempLocalHighC = 40.0F;
};

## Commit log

2026-06-28 docs: enrich drum filter controller specification
2026-06-30 Expand documentation for drum filter controller
2026-07-03 Met a jour la documentation projet
2026-07-05 Update docs data for temperature monitoring
2026-07-06 Document cable sections and upstream breaker
2026-07-07 Implement firmware MVP V0.1 simulation flow
2026-07-07 Document FT-0001 host-side test traceability
2026-07-09 Expand docs data for V1 firmware and temperature support
2026-07-14 Update firmware docs for KC868-A16 porting
    [couronne_assemblée.SLDASM, couronne_partie.3mf, couronne_partie.SLDPRT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]
2026-07-15 Update firmware workflow for KC868-A16 targets
    [DIN_Rail_Cable_Clamp.step, adaptateur_DIN_porte_fusible.SLDPRT, support_DIN_tenon.3mf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]
2026-07-15 Update documentation and refresh DIN support CAD assets
    [adaptateur_DIN_porte_fusible.SLDPRT, porte_fusible.3mf, porte_fusible.SLDPRT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]
2026-07-23 Document DS18B20 temperature sensor validation
2026-07-23 Validate shared RTC and LCD I2C bus on KC868-A16
